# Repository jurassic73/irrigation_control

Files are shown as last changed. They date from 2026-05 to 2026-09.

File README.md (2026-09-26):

# Irrigation Control

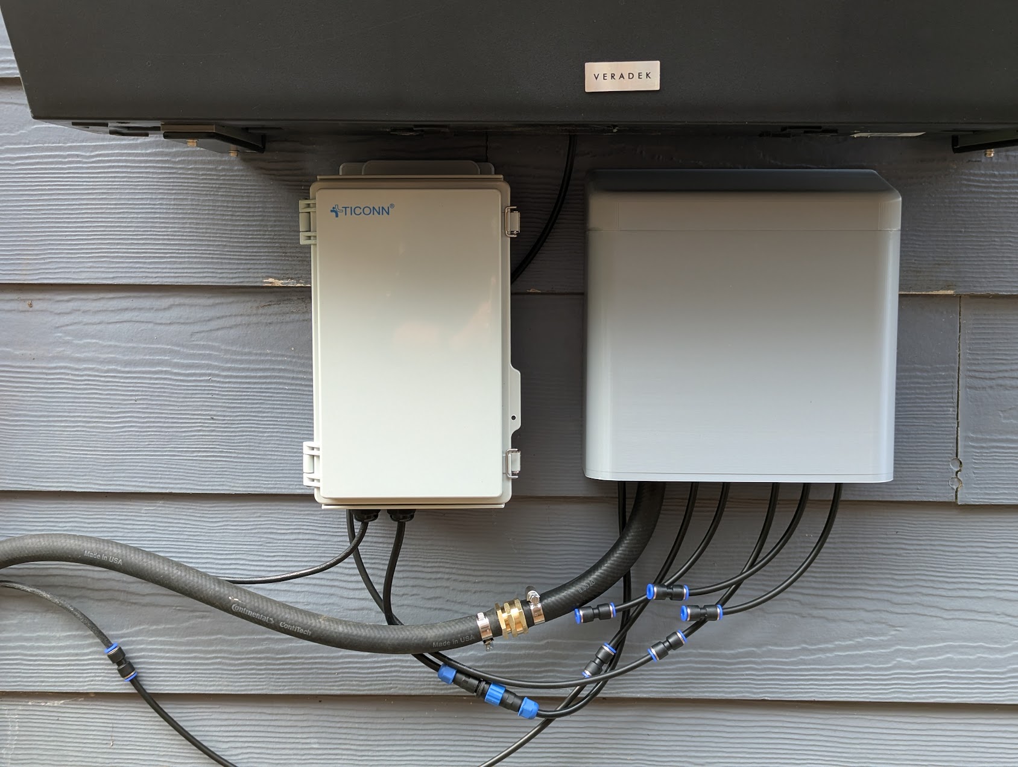
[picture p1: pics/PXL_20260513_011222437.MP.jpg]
Finished installation — control enclosure (left) and 3D printed solenoid valve enclosure (right) mounted on exterior wall


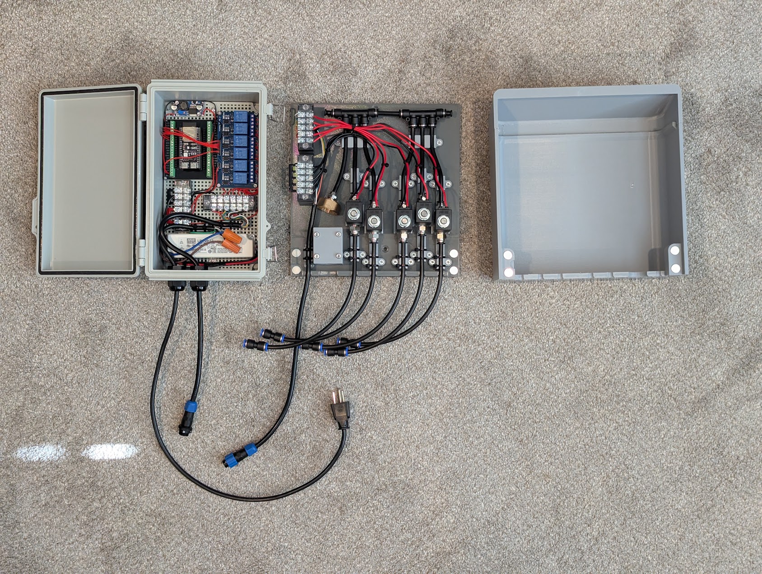
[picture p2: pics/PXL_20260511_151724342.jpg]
Build shot — control enclosure open (left), solenoid valve enclosure open (center), and 3D printed cover (right)


ESP32-S3 based irrigation controller with a mobile-friendly web UI. Controls up to 5 zones via relay board, enforces single-zone water pressure constraint via a FIFO queue, and runs two daily watering programs (Morning / Afternoon).

## Hardware

| Component | Detail |
| --- | --- |
| MCU | ESP32-S3-DevKitC-1-N8 |
| Status LED | WS2812 on GPIO 48 (onboard) |
| Relay outputs | GPIO 4, 5, 6, 7, 15 (active-low) |
| Relay board | 5-channel optocoupler relay, 12 V coils, 5 V logic VCC |
| Flow sensor | DIGITEN FL-S402B on GPIO 16 — Red→3.3 V, Black→GND, Yellow→GPIO 16 |

### LED status colors

- Green — standby, WiFi connected
- Blue — zone actively watering
- Off — booting / no WiFi

**Wiring note:** Use 5 V for relay board VCC (not 3.3 V). Disconnect USB-C before powering relays from 12 V supply.

**Plumbing note:** Apply Teflon tape to all NPT threaded fittings before installing into solenoid valves. Finger-tight connections will leak.

**Electronics enclosure note:** The TICONN box is waterproof and airtight, protecting all electronics from the elements. It hangs on a hook and connects via the AC cord and the 6-pin waterproof quick-disconnect, making it removable in seconds — if you need to bring it inside to update firmware, unplug both connections and take it in. Use the right USB-C port to flash code with no button pressing required.

**Valve enclosure note:** All valve housing connectors exit as quick-disconnects outside the housing. If you need to remove the enclosure for service, everything unplugs cleanly without disturbing the internal wiring.

**Chip temperature note:** On hot days the on-chip die temperature can read around 160 °F (71 °C). This is well within the ESP32-S3's maximum junction temperature spec of 125 °C (257 °F). At first glance 160 °F looks alarming, but it is normal and consistent with what other ESP32 users report when running inside an airtight enclosure exposed to direct sun.

## Parts List

Prices are approximate and subject to change.

### Electronics

| Image | Part | Description | ~Price | Link |
| --- | --- | --- | --- | --- |
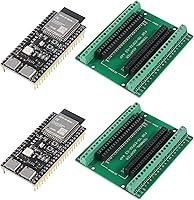
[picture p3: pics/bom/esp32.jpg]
ESP32-S3 dev board
|  | ESP32-S3 dev board | ESP32-S3-WROOM-1, 2-pack | ~$16 | [Amazon B0FF3XC4RZ](https://www.amazon.com/dp/B0FF3XC4RZ) |
| 12V power supply | 12 V power supply  | Powers relay coils and solenoid valves | ~$13 | [Amazon B00MEKJ4E2](https://www.amazon.com/dp/B00MEKJ4E2) |
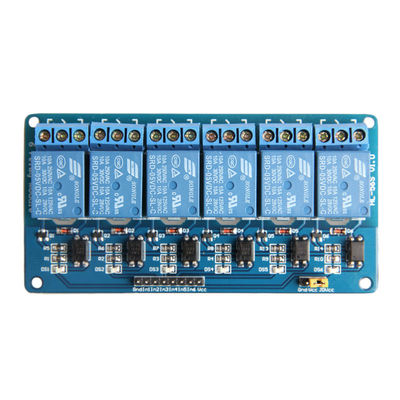
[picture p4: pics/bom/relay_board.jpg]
5-ch relay board
|  | 5-ch relay board | 5V optocoupler relay, 12 V coils | ~$5 | [AliExpress](https://www.aliexpress.us/w/wholesale-5v-relay-board-optocoupler.html) |
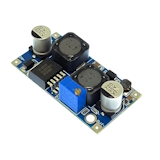
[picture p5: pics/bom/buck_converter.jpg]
Buck converter
|  | Buck converter | 12 V → 5 V step-down (powers ESP32) | ~$3 | [AliExpress](https://www.aliexpress.us/w/wholesale-step-down-buck.html) |
| Hall effect flow sensor | Flow sensor | DIGITEN FL-S402B, 1/4″ quick-connect, 0.3–10 L/min Hall effect — GPIO 16 | ~$9.50 | [Amazon search](https://www.amazon.com/s?k=1%2F4+Quick+Connect+0.3-10L%2Fmin+Water+Hall+Effect+Flow+Sensor+Meter) |

### Enclosure & Wiring

| Image | Part | Description | ~Price | Link |
| --- | --- | --- | --- | --- |
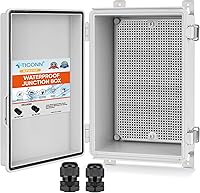
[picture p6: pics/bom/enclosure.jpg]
Waterproof enclosure
|  | Waterproof enclosure | TICONN IP67 ABS box, 10.2″ × 6.3″ × 3.9″, hinged lid, cable glands | ~$24 | [Amazon B0BND8Y3QN](https://www.amazon.com/dp/B0BND8Y3QN) |
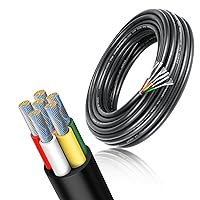
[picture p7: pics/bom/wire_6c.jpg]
6-conductor wire
|  | 6-conductor wire | RESHAKE 22 AWG 6C tinned copper stranded wire, 16.4 ft — zone wiring between enclosures | ~$12 | [Amazon B0C7MKBFNK](https://www.amazon.com/dp/B0C7MKBFNK) |
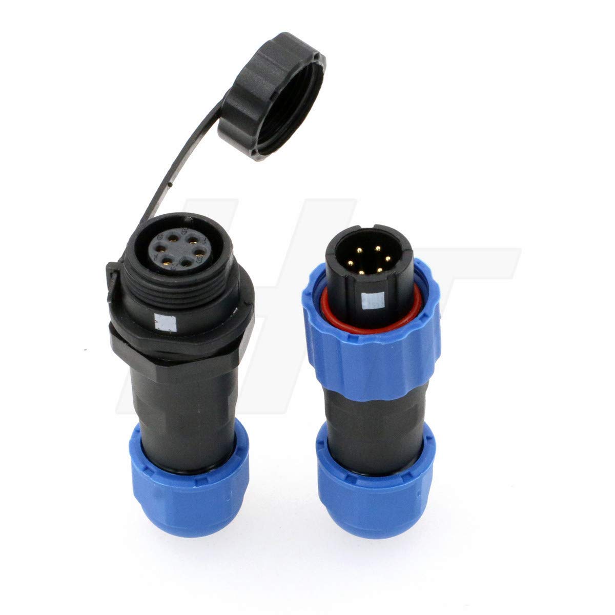
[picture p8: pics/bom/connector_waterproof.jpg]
Waterproof connector
|  | Waterproof connector | HangTon SD13 6-pin IP68 male/female plug set — inter-enclosure quick-disconnect | ~$12 | [Amazon B0894SSPVX](https://www.amazon.com/dp/B0894SSPVX) |
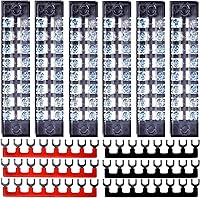
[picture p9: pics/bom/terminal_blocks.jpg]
Terminal blocks
|  | Terminal blocks | 12-pc screw terminal strip set, 600 V / 15 A | ~$10 | [Amazon B09QHSLJJ3](https://www.amazon.com/dp/B09QHSLJJ3) |

### Plumbing

System uses 1/4″ OD push-to-connect tubing throughout. One solenoid valve per zone.

| Image | Part | Description | ~Price | Link |
| --- | --- | --- | --- | --- |
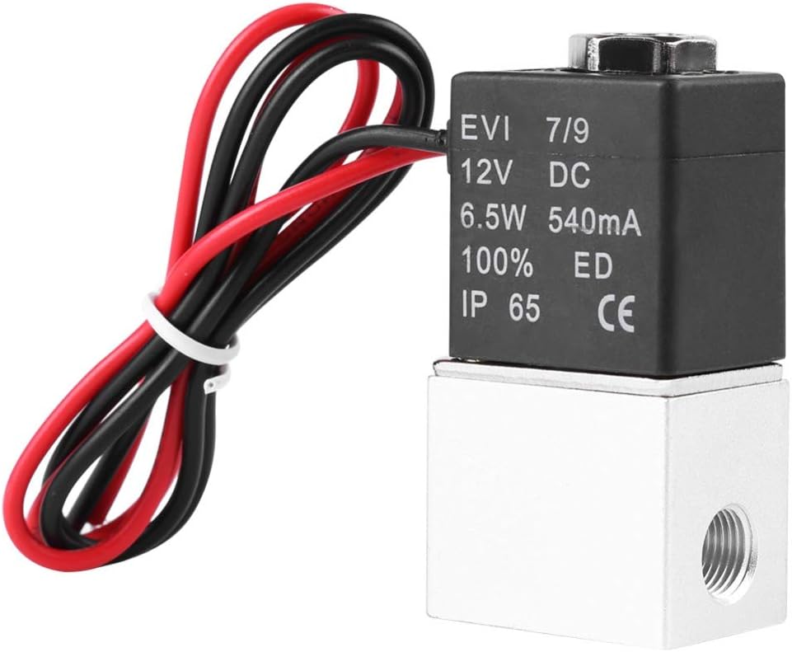
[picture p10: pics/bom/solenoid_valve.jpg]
Solenoid valve
|  | Solenoid valve | 12 V DC NC, 1/4″ NPT — one per zone | ~$10 each | [Amazon B07N2LGFYS](https://www.amazon.com/dp/B07N2LGFYS) |
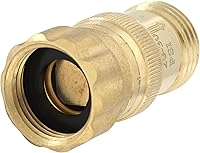
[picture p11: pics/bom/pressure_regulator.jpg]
Pressure regulator
|  | Pressure regulator  | 25 psi, 3/4″ hose thread, lead-free brass — protects drip system | ~$13 | [Amazon B0B1M42TVG](https://www.amazon.com/dp/B0B1M42TVG) |
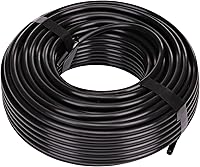
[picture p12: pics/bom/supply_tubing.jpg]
Supply tubing
|  | Supply tubing | Raindrip 1/4″ OD black poly, 100 ft — smooth outer layer for push-to-connect compatibility | ~$10 | [Amazon B0007WJIJU](https://www.amazon.com/dp/B0007WJIJU) |
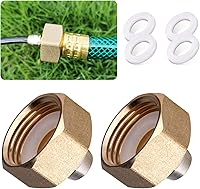
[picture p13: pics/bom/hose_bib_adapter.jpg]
Hose bib adapter
|  | Hose bib adapter | HOMENOTE 3/4″ female hose thread → 1/4″ tubing, 2-pack | ~$9 | [Amazon B089ZZPXLQ](https://www.amazon.com/dp/B089ZZPXLQ) |
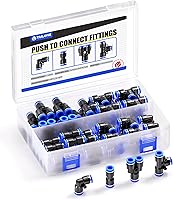
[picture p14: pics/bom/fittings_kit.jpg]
Fittings kit
|  | Fittings kit | TAILONZ 40-pc 1/4″ OD assortment — tees, elbows, straights, splitters | ~$14 | [Amazon B07RSLDDBR](https://www.amazon.com/dp/B07RSLDDBR) |
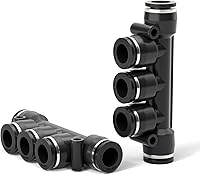
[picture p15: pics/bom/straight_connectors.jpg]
Straight connectors
|  | Straight connectors | TAILONZ 1/4″ OD push-to-connect, 5-pack | ~$9 | [Amazon B07SXRL8YR](https://www.amazon.com/dp/B07SXRL8YR) |
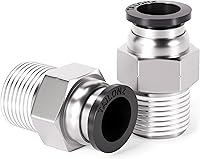
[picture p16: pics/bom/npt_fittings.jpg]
NPT male fittings
|  | NPT male fittings | TAILONZ 1/4″ OD × 1/4″ NPT male straight, 10-pack | ~$11 | [Amazon B07PBPB367](https://www.amazon.com/dp/B07PBPB367) |
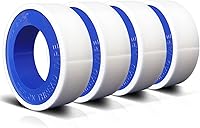
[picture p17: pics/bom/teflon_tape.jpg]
Teflon tape
|  | Teflon tape | PTFE thread seal tape, 1/2″ wide, 4-pack — for all NPT fittings | ~$5 | [Amazon B091913Z7F](https://www.amazon.com/dp/B091913Z7F) |

## 3D Printed Parts

The solenoid valve enclosure consists of two pieces, a base and a cover. Both consist of two parts due to my MK4s bed size. Used PETG for both as ASA warped too much to produce reliable, dimensionally accurate parts. I used Overture Space Gray PETG. The cover uses 12 mm rare earth magnets to secure when closed. Super glue holds the magnets in their holes.

The valve assembly parts are intentionally designed as separate, individually replaceable pieces.

The parts are segmented to fit the MK4s print bed. If you have a larger-format printer, open the STEP file (`stl/1_4_drip_irrigation_valve_housing.step`) in your CAD program to merge the halves into single pieces and clean up the seams. Always room for improvement — adapt it to your setup and submit a PR.

| Part | Perimeters | Infill |
| --- | --- | --- |
| Cover | 3 | 15% |
| Base (×2 halves) | 4 | 35% |
| Everything else | 2 | 15% |

### Assembly

1. **Base halves** — lightly tap the two halves together with a hammer until seated, then apply super glue along the seam to join permanently.
2. **Hardware mounting** — use wood screws to mount all hardware. 5/8″ screws work well for most mounting points.

## Commissioning Notes

### NPT fitting leaks

When I first pressurized the system I found leaks at three of the ten NPT fittings. Fix: depressurize the system, remove all five solenoids, and apply two full wraps of Teflon tape to every NPT fitting before reinstalling. Do them all at once rather than chasing leaks one at a time.

### Solenoid valve body leak

If water drips from the black valve body itself (not from a fitting), the internal o-ring needs reseating. To service:

1. Depressurize the system.
2. Remove the retaining nut — hand-tight, as it holds the solenoid coil on the cylinder but creates no seal. No torque needed.
3. Remove the solenoid coil.
4. Remove the two screws securing the end plate and pull the plate off.
5. Pull the cylinder out of the valve body.
6. Apply a thin coat of Super Lube synthetic silicone grease to the o-ring at the base of the cylinder.
7. Press the cylinder back into the valve body. Once fully seated, rotate it left and right about 90° to help the greased o-ring seat evenly and form a good seal.
8. Reinstall the end plate with the two screws.
9. Reinstall the solenoid coil and thread the retaining nut hand-tight. The end plate and its two screws handle all sealing — the nut retains the coil, nothing more.

## Software

- Framework: Arduino via PlatformIO
- Async HTTP server (ESPAsyncWebServer)
- Config persisted in NVS (ESP32 Preferences) — nonvolatile memory that survives firmware upgrades, so your zone names, schedules, and settings are safe when you flash new code
- Run, temperature, weather and change logs persisted to LittleFS — these also survive a firmware flash
- Embedded single-file HTML/CSS/JS UI served from PROGMEM

### Resource usage (current build)

| | Used | Available | % |
| ----- | --- | --- | --- |
| RAM | 57 KB | 320 KB | 18% |
| Flash | 1,075 KB | 3,264 KB  | 33% |

## Setup

1. Install [PlatformIO](https://platformio.org/).
2. Copy `src/secrets.h.example` to `src/secrets.h` and fill in your WiFi credentials:

   ```cpp
   const char* WIFI_SSID = "your_ssid";
   const char* WIFI_PASS = "your_password";
   ```
3. Copy `src/location.h.example` to `src/location.h` and fill in your coordinates (used for weather-based watering adjustments):

   ```cpp
   #define WEATHER_LAT  45.633   // your latitude
   #define WEATHER_LON -122.490  // your longitude
   ```

   Both `secrets.h` and `location.h` are gitignored so your credentials and location stay off GitHub.

5. Connect the ESP32-S3 via the **right USB-C port** (labeled USB on the board). This port uses native USB and handles bootloader mode automatically — no button pressing required for uploads or reboots. The left port (UART) requires holding BOOT then pressing RESET to enter download mode.
6. Build and upload:

   ```text
   pio run --target upload
   ```
7. Open a browser to the ESP32's IP address (printed on serial at 115200 baud).

## Web UI

The web UI runs directly on the ESP32 — no app, no cloud, no external server. Open a browser on any device on the same network and you're in. If your router supports VPN (such as WireGuard or OpenVPN), you can VPN into your home network from anywhere and access the controller as if you were home.

### Zones

Each zone appears as a card showing its name, active status, and a **Run Now** button. When a zone has a duration configured for a program, a colored pill label shows the program name and duration at a glance. Below the pill labels, a row of day buttons shows which days that zone participates in that program — blue for Morning, violet for Afternoon. Day buttons are read-only when collapsed.

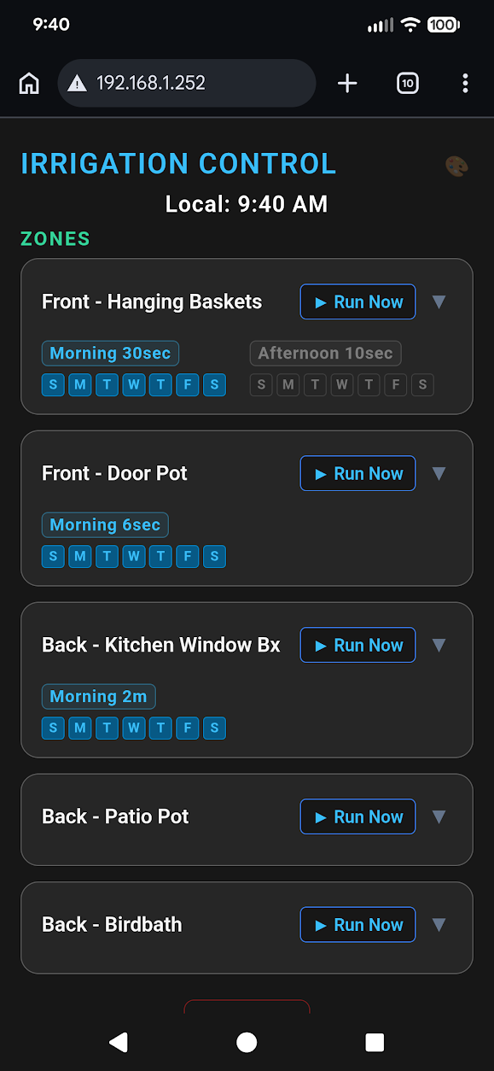
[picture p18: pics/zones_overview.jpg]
Zone list — collapsed view showing pill labels and day-of-week indicators
> 

At the right-hand end of the day-button row, a **power switch** parks the zone for
the season. Switched off, the zone is skipped by both scheduled runs and program
**Run Now**, but its durations and day masks are kept exactly as they were — so the
timings you dialled in over the summer are still there next spring. A parked zone
renders greyed out. A single-zone **Run Now** still works as an explicit manual
override, so you can always test a parked zone.

Tap the arrow to expand a zone. The day buttons become interactive so you can toggle individual days per program. The duration inputs let you set minutes and seconds independently for Morning and Afternoon.

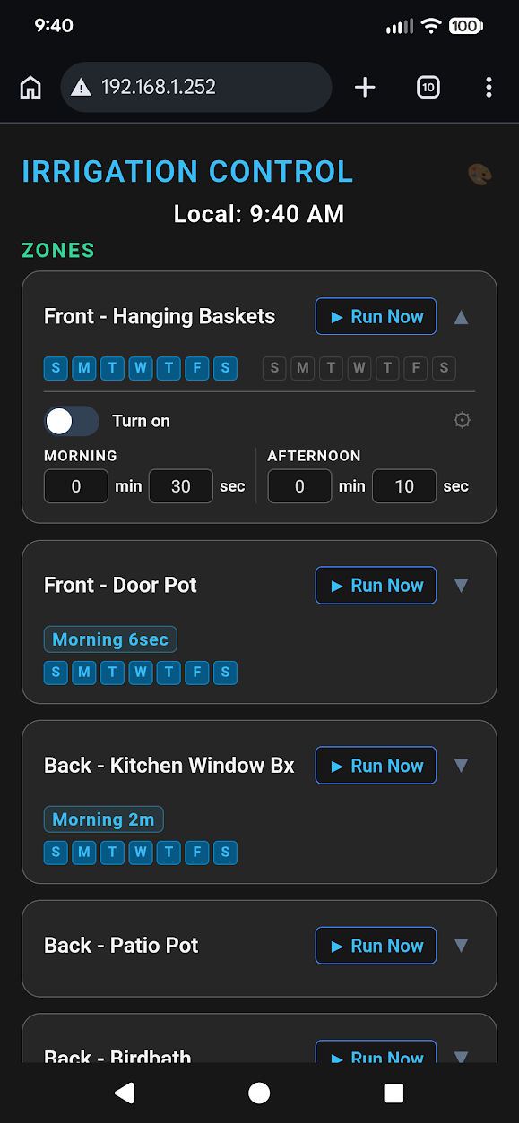
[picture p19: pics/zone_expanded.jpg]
Zone expanded — duration inputs and interactive day toggles
> 

Tap the gear icon inside an expanded zone to open the configuration panel where you can rename the zone and change its GPIO pin.

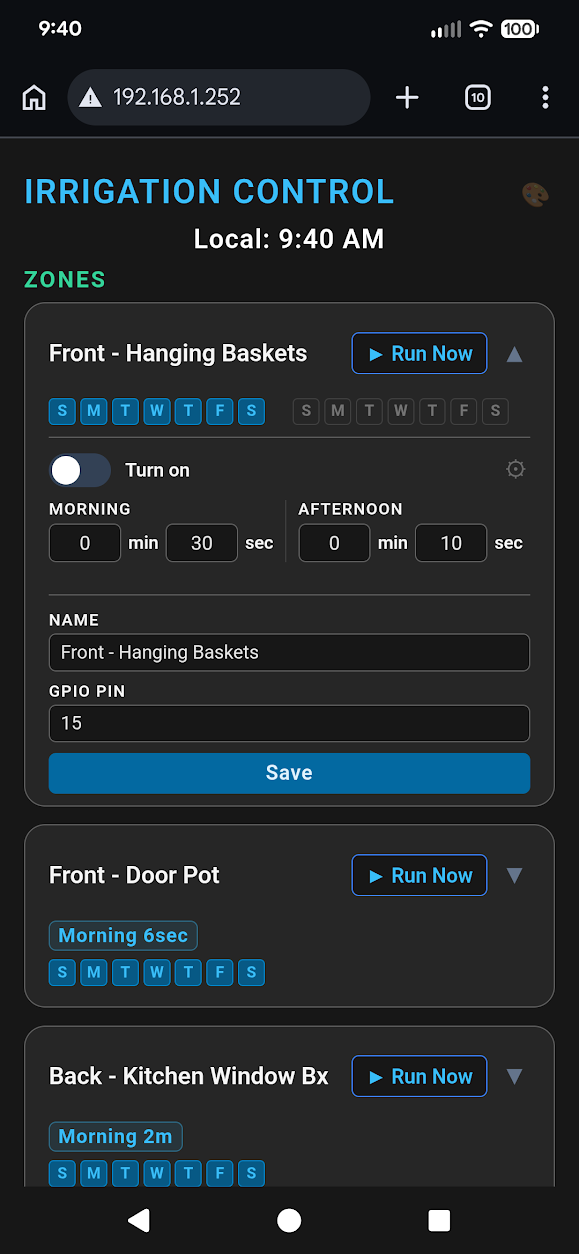
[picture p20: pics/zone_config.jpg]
Zone expanded — name and GPIO pin configuration
> 

### Run Now

Tap **Run Now** on any zone to open the run dialog. It offers that zone's configured
Morning and Afternoon durations as one-tap presets — colour-matched to the schedule
pills — or tap **Custom** to dial in an exact duration.

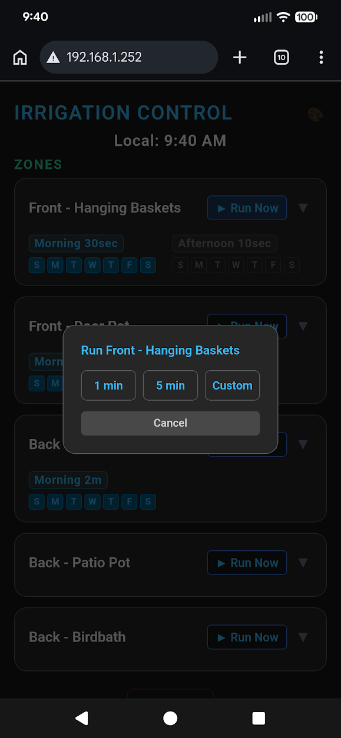
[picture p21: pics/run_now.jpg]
Run Now — quick-select presets
> 

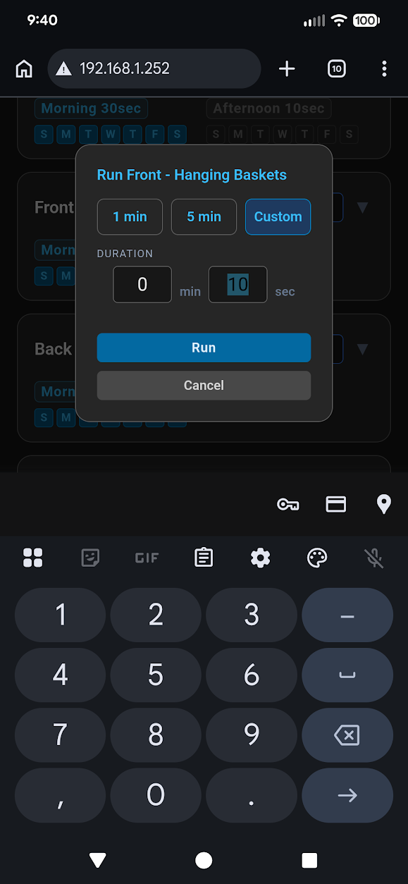
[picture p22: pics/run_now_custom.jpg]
Run Now — custom duration entry
> 

The zone is queued immediately. All other Run Now buttons disable while any zone is running or queued to prevent pressure conflicts. Use **All Off** to stop the active zone and clear the queue instantly.

### Programs

Two watering programs — Morning and Afternoon — each have an independent time, day-of-week mask, and enable toggle. Changes save to flash automatically when you interact with any control.

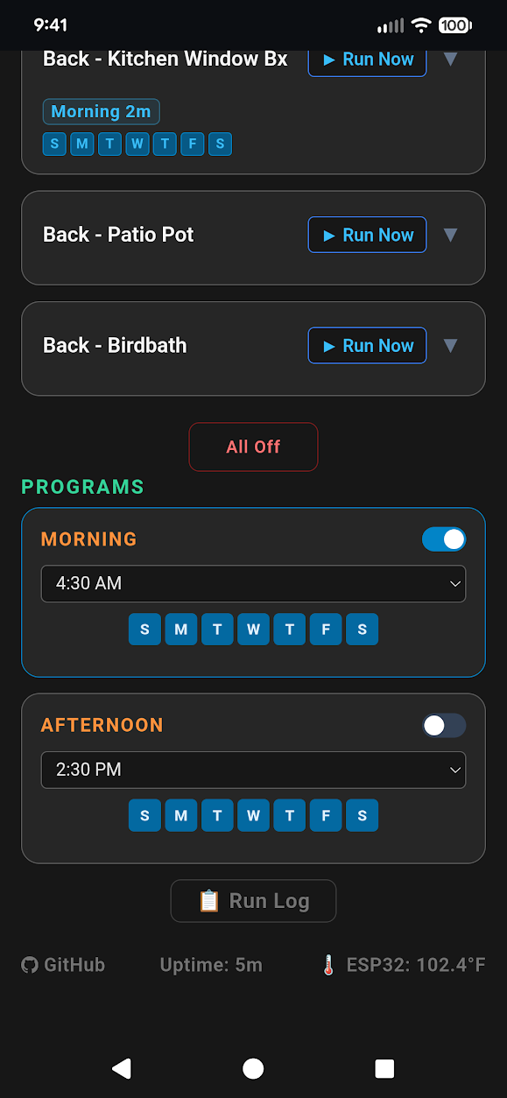
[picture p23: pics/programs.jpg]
Programs — Morning enabled at 4:30 AM daily, Afternoon disabled
> 

Each zone independently opts in or out of a program on a per-day basis using the day toggles on the zone card. A zone only waters when **both** the program's day mask **and** the zone's own day mask include that day of the week. This lets you run some zones every day while others water only on certain days, all within the same program schedule.

### Flow Monitoring

The flow sensor measures actual water delivered per zone run, auditing for upstream pressure problems (failing pressure regulator, supply starvation) and per-zone issues (clogged drip emitters, broken lines).

#### Wiring

Install the sensor inline on the main supply line — upstream of the solenoid valves so all zones flow through it.

| Wire | Connect to |
| --- | --- |
| Red | 3.3 V |
| Black  | GND |
| Yellow | GPIO 16 (signal)|

**Sensor spec (DIGITEN FL-S402B):** F = 23 × Q(L/min) — approximately 1,380 pulses/liter or **~5,220 pulses/gallon** theoretical. Always run the in-app calibration for your specific installation; actual values vary with pressure and fittings.

#### Calibration

1. Wire the sensor and flash firmware with flow sensor support enabled.
2. Open the web UI and tap **Flow Cal** (to the right of the weather badge).
3. Select the zone to run during calibration (defaults to Zone 5). Choose a zone that flows through the sensor.
4. Verify **Flow Sensor GPIO Pin** is set to **16**.
5. Have a clean 1-gallon measuring jug ready at the zone outlet.
6. Tap **▶ Start Cal** — the selected zone turns on and pulse counting begins.
7. Allow water to flow until the jug reaches exactly **1 gallon**, then tap **■ Stop Cal**.
8. The zone stops and the counted pulses auto-populate the **Pulses per Gallon** field. Review and adjust if needed.
9. Set your **Low-flow alarm threshold** (default 75% — alarm triggers when a run delivers less than 75% of the baseline flow rate).
10. Tap **Save**.

#### Baseline learning and low-flow alarms

After calibration, the firmware auto-learns a per-zone flow baseline from the first 3 valid runs (runs ≥ 30 seconds with measured flow). Progress is shown in the Flow Cal modal next to each zone name.

Once a baseline is established for a zone:

- If a run's flow rate drops **below the alarm threshold** (default 75% of baseline), a persistent red banner appears at the top of the page on the next visit: **"Low flow detected: Zone X — possible upstream pressure issue or clogged emitters. Check run logs."**
- The banner is dismissible for the current session, but reappears on the next page load until the alarm clears.
- When subsequent runs return to within spec, the alarm **clears automatically**.
- To reset a zone's baseline (e.g., after intentionally changing emitters), open **Flow Cal**, select the zone, and tap **Reset Baseline for Selected Zone**.

The **Flow Adjustment row** below the weather badge shows today's and this week's total gallons delivered across all zones, along with the active GPIO pin and pulses/gallon setting. It is hidden until the sensor is calibrated.

The **Run Log** shows a blue gallon figure next to each run's duration once flow data
is available, and the CSV export includes a **Water (gal)** column. Volumes are stored
to the hundredth of a gallon and displayed with two decimals below 1 gal, because drip
zones routinely deliver 0.03–0.7 gal per run — at tenth-gallon resolution most runs
recorded as `0.0`, which also made the low-flow check see zero flow and raise false
alarms. The low-flow rate is computed from raw sensor pulses rather than the rounded
volume, so display precision and alarm accuracy are independent.

Retention is set from the **Keep _n_ days** field in the Run History panel header
(1–90 days, default 7).

### Additional features

- **All Off** — stops the active zone and clears the entire queue.
- **Run countdown** — the active zone's badge counts down the time remaining, ticking every second between the 15-second state polls.
- **Run Log** — opens a modal showing watering history grouped by day and program, newest first. Includes per-run gallon measurements once the flow sensor is calibrated.
- **Chip temperature** — live ESP32 die temperature in the bottom bar. Tap to open a history graph with **1 Day** and **1 Week** views. Auto-refreshes every 60 seconds while open. Samples recorded every 10 minutes (up to 1,008, persisted to LittleFS so they survive a reboot).
- **Uptime** — time since last boot, updated every 15 seconds.
- **Theme** — 🎨 icon cycles dark → light → color. Preference saved in localStorage.

## API Endpoints

**Read-only endpoints are `GET`. Every state-changing endpoint is `POST`.** A `GET`
against a `POST` endpoint returns 404. This keeps a stray `<img src="http://host/alloff">`
on some other page — or a link prefetcher, or a crawler — from actuating a valve.
Parameters still travel in the query string either way, so `POST /relay?id=0&state=1`
needs no request body.

### Read (GET)

| Endpoint | Params | Description |
| --- | --- | --- |
| `/` | — | The web UI, with the current state inlined so the first paint needs no round trip |
| `/config` | — | JSON snapshot of full state — see fields below |
| `/history` | — | Run history, newest first; includes `retainDays` and `count` |
| `/changelog` | — | Configuration change log, up to 50 entries |
| `/weatherlog` | — | Last 7 weather fetches, newest first, successes and failures |
| `/temp` | — | Current chip die temperature as `{"c": 52.3, "f": 126.1}` |
| `/temphistory` | `secs` (default 604800) | Temperature samples at 10-min intervals — up to 144 for 24 h, up to 1008 for 7 days |
| `/flowcal/stop`  | — | Returns `{"pulses": N}` — the value to use as pulses/gallon. Reads the counter; does not stop it  |

### Write (POST)

| Endpoint | Params | Description |
| --- | --- | --- |
| `/relay` | `id`, `state` (0/1), `secs` (optional) | Queue a zone, or stop it and drop it from the queue. `secs`, not minutes |
| `/alloff` | — | Stop the active zone and clear the queue |
| `/runprogram` | `id` | Queue a program's zones immediately, skipping switched-off zones |
| `/setzone` | `id`, `name`, `pin`, `en`, `d0`…`dN`, `zd0`…`zdN` | Zone name, GPIO pin, power switch, per-program durations **in seconds**, per-program day masks |
| `/sethistory` | `days` | Retention window, 1–90 days. Also settable from the Run History panel header |
| `/setprogram` | `id`, `en`, `h`, `m`, `days` | Program enable, time and day mask (bit 0 = Sunday) |
| `/setcoolpct` | `pct` | Cool-day watering percentage, 10–90 |
| `/sethotpct` | `pct` | Hot-day watering percentage, 100–200 |
| `/setweatherconds` | `htf`, `hwk`, `hof`, `ctf`, `ccp`, `cpx` | Hot/cool thresholds: temp °F, wind kph, override °F, cool °F, cloud %, precip ×10 mm |
| `/fetchweather` | — | Trigger an immediate weather fetch on the background task |
| `/pushcl` | `e` (URL-encoded JSON) | Append a change-log entry |
| `/clearcl` | `confirm=1` | Erase the change log. Without `confirm=1` returns 400 — it is destructive |
| `/flowcal/start` | — | Zero the pulse counter before filling the calibration jug |
| `/setflow` | `pin`, `ppg` | Flow sensor GPIO pin and pulses-per-gallon |
| `/setflowthresh` | `pct` | Low-flow alarm threshold, 10–99; default 75 |
| `/dismissflowalarm` | — | Hide the current low-flow banner until a fresh alarm occurs |
| `/resetflowbaseline`  | `zone` | Clear one zone's baseline and alarm; re-learns over the next 3 runs |

### `/config` fields of note

| Field | Meaning |
| --- | --- |
| `activeZone` | Index of the running zone, or `-1` |
| `activeEnd` | Unix time the active run ends, or `0` — drives the countdown on the zone badge |
| `queued` | Zone indices waiting, in order |
| `chipF` | Chip die temperature in °F |
| `weatherScale` | Active watering percentage, 100 unless the day read hot or cool |
| `zones[].enabled` | `false` when the zone's power switch is off — durations are retained |
| `zfBase` / `zfCnt` | Per-zone flow baseline (gal/min ×100) and how many learning runs have landed |

### `/history` response example

```json
{
  "retainDays": 7,
  "count": 3,
  "history": [
    {
      "zone": 2,
      "name": "Back Garden",
      "trigger": "Morning",
      "start": 1746000000,
      "durationSecs": 300,
      "gallonsX100": 237,
      "lowFlow": 0
    }
  ]
}
```

### `/temphistory` response example

```json
[
  {"t": 1746000000, "f": 124.3},
  {"t": 1746000600, "f": 125.1}
]
```

## Failure Behaviour

An irrigation controller fails badly if it leaves a valve open, so the firmware is
arranged to end up with the water off:

- **Hung firmware** — `loopTask` is subscribed to the ESP32 task watchdog (5 s, panic
  mode). If the main loop ever wedges, the chip reboots, and `setup()` drives every
  relay off before it touches anything else.
- **Power loss** — the solenoids are normally-closed, so no power means no water.
- **Router down at boot** — the boot-time WiFi wait is bounded at 60 s. The controller
  finishes booting without a network and `loop()` retries every 30 s, so a power cut
  that takes the router down alongside the controller recovers on its own.
- **NTP unavailable** — schedules pause rather than firing at the wrong time, and
  resume automatically once the clock syncs, however late that is.
- **Run length** — capped at `MAX_RELAY_SECS` (8 h) after weather scaling, not before.

## Scheduling

A single water pressure source means one relay runs at a time. The scheduler uses a FIFO queue:

- When a program fires it enqueues all enabled zones back-to-back.
- A manual Run Now enqueues that zone at the head of the queue.
- Turning a zone off removes it from the queue and stops it if active.

Run history lives in a 200-entry circular buffer, mirrored to LittleFS (`hist.bin`) so
it survives a reboot, and purges to the configured retention window after each run.

Writes to flash are deferred: HTTP handlers run on the async server task, which must
not block, so they flag what changed and the main loop performs the NVS and LittleFS
writes on its next pass.

A zone waters only when its power switch is on, the program's day mask includes today,
**and** the zone's own day mask includes today.

## File Structure

```text
irrigation_control/
├── platformio.ini
├── partitions.csv            # 8 MB layout: dual OTA app slots + 1.5 MB LittleFS
├── irrigation-widget.html    # Standalone desktop widget (reads /config and /temp)
├── src/
│   ├── main.cpp              # All firmware + embedded HTML UI
│   ├── secrets.h             # WiFi credentials (gitignored)
│   ├── secrets.h.example
│   ├── location.h            # Latitude/longitude for weather (gitignored)
│   └── location.h.example
├── stl/                      # 3D-printable enclosure parts
├── pics/                     # README screenshots and BOM thumbnails
└── README.md
```

Logs are kept on the LittleFS partition as `hist.bin`, `temp.bin`, `wlog.bin` and
`clog.json`. Flashing firmware leaves them alone; writing a filesystem image with
`pio run -t uploadfs` would erase all four.

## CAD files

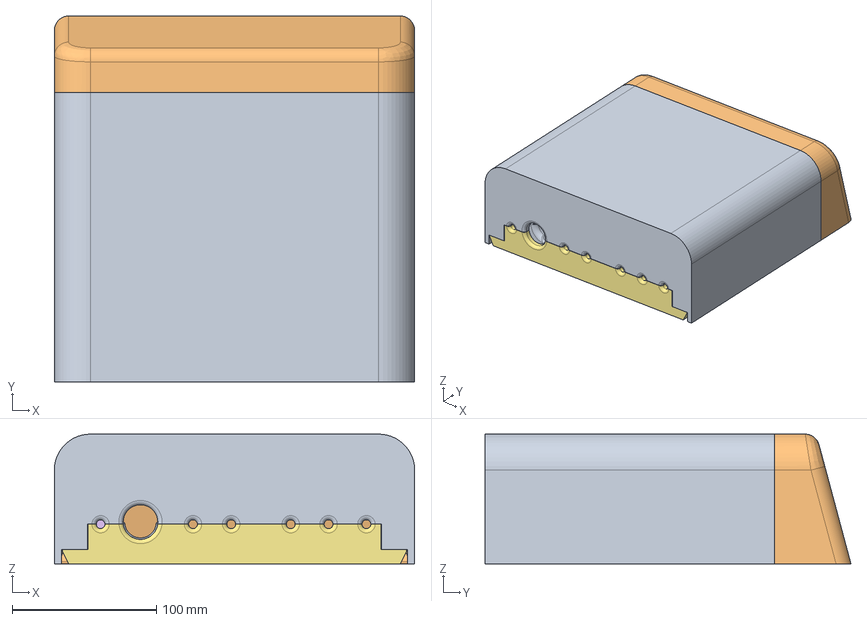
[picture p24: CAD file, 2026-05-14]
stl/1_4_drip_irrigation_valve_housing.step
250.0 x 253.9 x 90.0 mm
hose_keeper_base (1)
hose_keeper_cap (1)

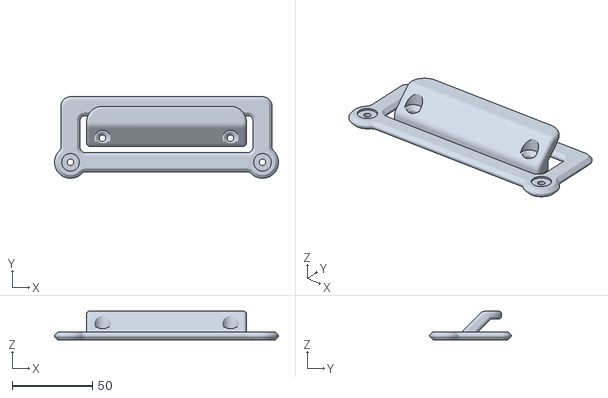
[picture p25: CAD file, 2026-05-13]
stl/box_hook.stl
140.0 x 51.0 x 18.0

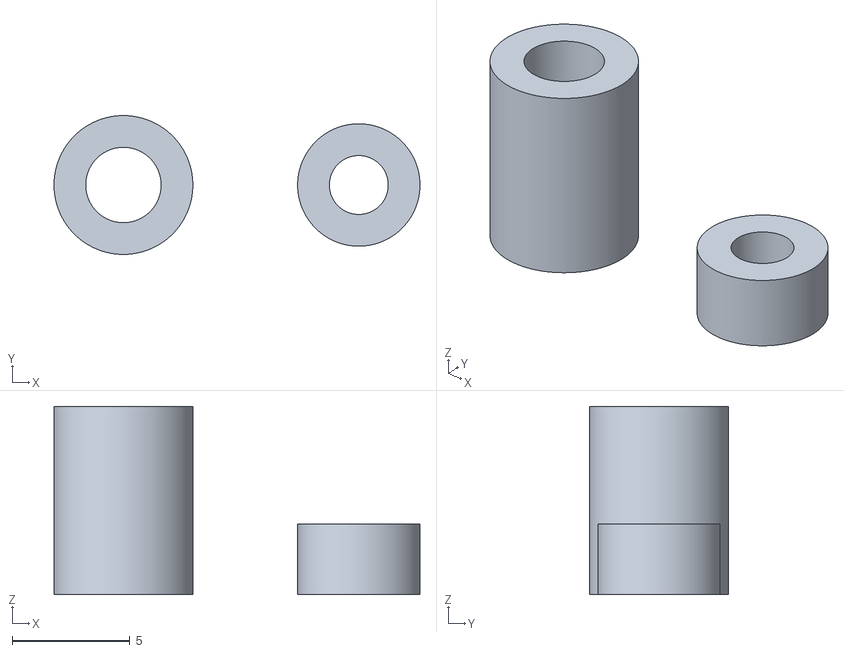
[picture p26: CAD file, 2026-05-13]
stl/board_spacers.stl
15.6 x 5.90 x 8.00

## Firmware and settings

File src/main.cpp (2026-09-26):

#include <Arduino.h>
#include <WiFi.h>
#include <AsyncTCP.h>
#include <ESPAsyncWebServer.h>
#include <Preferences.h>
#include <LittleFS.h>
#include <time.h>
#include <Adafruit_NeoPixel.h>
#include <HTTPClient.h>
#include <WiFiClientSecure.h>
#include <ArduinoJson.h>
#include "secrets.h"
#include "location.h"

#define FW_VERSION        "1.2.1"

#define LED_PIN      48
#define LED_COUNT     1
#define NUM_ZONES     5
#define NUM_PROGRAMS  2
#define QUEUE_MAX    (NUM_ZONES * NUM_PROGRAMS)

#define MAX_RELAY_SECS   28800UL   // 8 hours — hard cap on any single zone run
#define WEATHER_SLEEP_MS (30UL * 60UL * 1000UL)  // 30-minute retry interval

Adafruit_NeoPixel led(LED_COUNT, LED_PIN, NEO_GRB + NEO_KHZ800);

const bool  RELAY_ACTIVE_LOW = true;
static const char* TZ_PACIFIC = "PST8PDT,M3.2.0,M11.1.0";

uint8_t relayPins[NUM_ZONES]      = {4, 5, 6, 7, 15};
char    relayNames[NUM_ZONES][32] = {"Zone 1","Zone 2","Zone 3","Zone 4","Zone 5"};

struct WateringProgram { bool enabled; uint8_t hour, minute, days; };
const char* PROG_NAMES[NUM_PROGRAMS] = {"Morning", "Afternoon"};
WateringProgram programs[NUM_PROGRAMS] = {
  {true,  5, 30, 0x7F},
  {true, 15, 30, 0x7F},
};
time_t progLastFired[NUM_PROGRAMS] = {};

uint16_t zoneDuration[NUM_ZONES][NUM_PROGRAMS] = {};
// bit i = zone i participates in scheduled runs. Switching a zone off preserves its
// durations and day masks — the point is parking a zone for the season without
// having to remember and re-enter last year's settings.
uint8_t  zoneEnabledBits = 0xFF;
uint8_t  zoneDays[NUM_ZONES][NUM_PROGRAMS]     = {};

struct QEntry { uint8_t zone; uint32_t secs; uint8_t trigger; }; // trigger: 0=manual, 1+=program id+1
QEntry  qBuf[QUEUE_MAX];
int     qHead = 0, qSize = 0;
int8_t  activeZone      = -1;
time_t  activeEndTime   = 0;
time_t  activeStartTime = 0;
uint8_t activeTrigger   = 0;

// ESPAsyncWebServer callbacks run on Core 0; loop() runs on Core 1.
// stateMux guards all shared queue and active-zone state between the two tasks.
// flowMux guards flowPulseCount between the FALLING-edge ISR and task context.
static portMUX_TYPE stateMux = portMUX_INITIALIZER_UNLOCKED;
static portMUX_TYPE flowMux  = portMUX_INITIALIZER_UNLOCKED;

#define HISTORY_MAX 200
// trigger byte: low 7 bits = trigger id (0=manual, 1+=program), bit 7 = low-flow detected this run
#define HIST_LOWFLOW 0x80
// gallonsX100 = hundredths of a gallon. Tenths truncated almost every drip-zone run
// to zero, which also fed checkFlowRate a zero rate and produced false low-flow alarms.
struct HistoryEntry { time_t start; uint16_t duration; uint8_t zone; uint8_t trigger; uint16_t gallonsX100; };
HistoryEntry history[HISTORY_MAX];
int histHead = 0, histCount = 0;
uint8_t historyDays = 7;

#define TEMP_HIST_MAX 1008
struct TempSample { time_t t; float c; };
TempSample tempHist[TEMP_HIST_MAX];
int tempHistHead = 0, tempHistCount = 0;
unsigned long lastTempSample = 0;

uint8_t coolDayPct    = 50;   // % to water on cool/overcast days (persisted)
uint8_t hotDayPct     = 150;  // % to water on hot/windy days (persisted)
uint8_t weatherScale  = 100;  // active scale factor — RAM only, resets to 100 on reboot
uint8_t hotTempF      = 90;   // hot-day min temp threshold °F (persisted)
uint8_t hotWindKph    = 24;   // hot-day min wind threshold kph (persisted)
uint8_t hotOverrideF  = 85;   // at/above this temp, cloud/low-temp can't force a cool day (persisted)
uint8_t coolTempF     = 65;   // cool-day max temp threshold °F (persisted)
uint8_t coolCloudPct  = 80;   // cool-day min cloud cover % (persisted)
uint8_t coolPrecipX10 = 25;   // cool-day min precip ×10 mm (25 = 2.5 mm) (persisted)
time_t  lastWeatherFetch = 0;
time_t  lastWeatherAttempt = 0;
volatile bool weatherFetchActive = false;
static TaskHandle_t weatherTaskHandle = NULL;

uint8_t  flowPin             = 16;
uint32_t flowPulsesPerGallon = 0;       // 0 = not calibrated
volatile uint32_t flowPulseCount = 0;
uint32_t activeStartPulses   = 0;

// Atomic snapshot of the ISR-updated pulse counter from task context.
static inline uint32_t readFlowPulses() {
  portENTER_CRITICAL(&flowMux);
  uint32_t v = flowPulseCount;
  portEXIT_CRITICAL(&flowMux);
  return v;
}

#define FLOW_BASELINE_RUNS 3            // runs needed to establish per-zone baseline
uint16_t zoneFlowBaseline[NUM_ZONES]    = {};  // gal/min * 100; 0 = still learning
uint8_t  zoneBaselineCount[NUM_ZONES]   = {};  // valid runs accumulated so far
uint32_t zoneBaselineSum[NUM_ZONES]     = {};  // sum of rateX100 during learning
uint8_t  zoneFlowAlarmBits              = 0;   // bitmask: bit i = zone i has low-flow alarm
uint8_t  zoneFlowAlarmDismissed         = 0;   // bitmask: bit i = alarm dismissed for this instance
uint8_t  flowAlarmThreshPct             = 75;  // alarm when flow < this % of baseline

#define WEATHER_LOG_MAX 7
struct WeatherLogEntry { time_t t; float maxF, precip, cloud, wind; uint8_t scale; bool ok; int16_t errCode; bool manual; };
WeatherLogEntry wLog[WEATHER_LOG_MAX];
int wLogCount = 0, wLogHead = 0;

String clJson = "[]";
SemaphoreHandle_t clMux = nullptr;  // guards clJson between HTTP callbacks and the deferred write
Preferences       prefs;
SemaphoreHandle_t prefsMux = nullptr;  // guards all Preferences access across cores
bool timeValid = false;  // set true only after a successful NTP sync

// ── Deferred persistence ──────────────────────────────────────────────────────
// ESPAsyncWebServer callbacks run on the AsyncTCP task, which must not block: a
// saveConfig() there is ~60 NVS keys and a saveHistoryLog() is a 2.4 KB LittleFS
// write, both stalling every other connection. Handlers set a dirty bit instead and
// loop() does the actual write on its next pass (flushDirty).

#define DIRTY_CONFIG   0x01
#define DIRTY_PURGE    0x02   // trim history to the retention window (runs before the write)
#define DIRTY_HISTORY  0x04
#define DIRTY_TEMP     0x08
#define DIRTY_WLOG     0x10
#define DIRTY_CLOG     0x20

static uint8_t dirtyFlags = 0;
static portMUX_TYPE dirtyMux = portMUX_INITIALIZER_UNLOCKED;

static void markDirty(uint8_t bits) {
  portENTER_CRITICAL(&dirtyMux);
  dirtyFlags |= bits;
  portEXIT_CRITICAL(&dirtyMux);
}

// ── Log persistence (LittleFS) ────────────────────────────────────────────────

void saveHistoryLog() {
  File f = LittleFS.open("/hist.bin", "w");
  if (!f) { Serial.println("saveHistoryLog: open failed"); return; }
  f.write((uint8_t*)&histHead,  sizeof(histHead));
  f.write((uint8_t*)&histCount, sizeof(histCount));
  f.write((uint8_t*)history,    sizeof(history));
  f.close();
  Serial.printf("saveHistoryLog: %d entries written\n", histCount);
}

void saveTempHistory() {
  File f = LittleFS.open("/temp.bin", "w");
  if (!f) { Serial.println("saveTempHistory: open failed"); return; }
  f.write((uint8_t*)&tempHistHead,  sizeof(tempHistHead));
  f.write((uint8_t*)&tempHistCount, sizeof(tempHistCount));
  f.write((uint8_t*)tempHist,       sizeof(tempHist));
  f.close();
  Serial.printf("saveTempHistory: %d entries written\n", tempHistCount);
}

void saveWeatherLog() {
  File f = LittleFS.open("/wlog.bin", "w");
  if (!f) { Serial.println("saveWeatherLog: open failed"); return; }
  f.write((uint8_t*)&wLogHead,  sizeof(wLogHead));
  f.write((uint8_t*)&wLogCount, sizeof(wLogCount));
  f.write((uint8_t*)wLog,       sizeof(wLog));
  f.close();
  Serial.printf("saveWeatherLog: %d entries written\n", wLogCount);
}

void saveChangeLog() {
  // clJson is mutated by /pushcl on the AsyncTCP task while this runs on loop()'s.
  if (clMux) xSemaphoreTake(clMux, portMAX_DELAY);
  File f = LittleFS.open("/clog.json", "w");
  if (f) { f.print(clJson); f.close(); }
  else Serial.println("saveChangeLog: open failed");
  if (clMux) xSemaphoreGive(clMux);
}

void loadLogs() {
  // Directory listing for diagnostics
  File root = LittleFS.open("/");
  if (root) {
    File entry = root.openNextFile();
    if (!entry) Serial.println("LittleFS: filesystem empty");
    while (entry) {
      Serial.printf("LittleFS: %s  %u bytes\n", entry.name(), entry.size());
      entry = root.openNextFile();
    }
    root.close();
  }

  auto loadBin = [](const char* path, void* a, size_t sa, void* b, size_t sb, void* c, size_t sc) {
    File f = LittleFS.open(path, "r");
    if (!f) { Serial.printf("loadLogs: %s not found\n", path); return; }
    size_t got = f.size(), expect = sa + sb + sc;
    if (got != expect) {
      Serial.printf("loadLogs: %s size mismatch (got %u expect %u)\n", path, got, expect);
      f.close(); return;
    }
    f.read((uint8_t*)a, sa);
    f.read((uint8_t*)b, sb);
    f.read((uint8_t*)c, sc);
    f.close();
  };

  loadBin("/hist.bin", &histHead, sizeof(histHead), &histCount, sizeof(histCount), history, sizeof(history));
  loadBin("/temp.bin", &tempHistHead, sizeof(tempHistHead), &tempHistCount, sizeof(tempHistCount), tempHist, sizeof(tempHist));
  loadBin("/wlog.bin", &wLogHead, sizeof(wLogHead), &wLogCount, sizeof(wLogCount), wLog, sizeof(wLog));

  // loadBin only validates file size, so head/count still come straight off flash.
  // A corrupt-but-right-sized file would otherwise index out of bounds: purgeHistory
  // and addHistory use histHead unwrapped, and a negative count makes
  // (head + count) % MAX negative. Drop the ring rather than trust garbage.
  auto clampRing = [](const char* what, int& head, int& count, int cap) {
    if (count < 0 || count > cap || head < 0 || head >= cap) {
      Serial.printf("loadLogs: %s ring invalid (head=%d count=%d cap=%d) — discarding\n",
                    what, head, count, cap);
      head = 0; count = 0;
    }
  };
  clampRing("hist", histHead,     histCount,     HISTORY_MAX);
  clampRing("temp", tempHistHead, tempHistCount, TEMP_HIST_MAX);
  clampRing("wlog", wLogHead,     wLogCount,     WEATHER_LOG_MAX);

  // Rescale tenths-of-a-gallon entries written before the precision fix, and drop the
  // flow baselines learned from them — those were derived from truncated volumes, so
  // checking accurate rates against them would misfire. They re-learn over 3 runs.
  {
    if (prefsMux) xSemaphoreTake(prefsMux, portMAX_DELAY);
    Preferences mp; mp.begin("irr", false);
    bool migrate = mp.getUChar("logVer", 0) < 1;
    if (migrate) mp.putUChar("logVer", 1);
    mp.end();
    if (prefsMux) xSemaphoreGive(prefsMux);
    if (migrate) {
      for (int i = 0; i < histCount; i++) {
        HistoryEntry& e = history[(histHead + i) % HISTORY_MAX];
        uint32_t v = (uint32_t)e.gallonsX100 * 10U;
        e.gallonsX100 = (uint16_t)(v > 65535U ? 65535U : v);
      }
      for (int z = 0; z < NUM_ZONES; z++) {
        zoneFlowBaseline[z] = 0; zoneBaselineCount[z] = 0; zoneBaselineSum[z] = 0;
      }
      zoneFlowAlarmBits = 0; zoneFlowAlarmDismissed = 0;
      Serial.printf("Log migration: rescaled %d entries to hundredths, reset flow baselines\n", histCount);
      markDirty(DIRTY_HISTORY | DIRTY_CONFIG);
    }
  }

  Serial.printf("Logs loaded: hist=%d temp=%d wlog=%d\n", histCount, tempHistCount, wLogCount);
  { File f = LittleFS.open("/clog.json", "r"); if (f) { clJson = f.readString(); f.close(); } }
}

void pushWeatherLog(time_t t, float maxF, float precip, float cloud, float wind, uint8_t scale, bool ok, int16_t errCode = 0, bool manual = false) {
  int idx = (wLogHead + wLogCount) % WEATHER_LOG_MAX;
  wLog[idx] = {t, maxF, precip, cloud, wind, scale, ok, errCode, manual};
  if (wLogCount < WEATHER_LOG_MAX) wLogCount++;
  else wLogHead = (wLogHead + 1) % WEATHER_LOG_MAX;
  markDirty(DIRTY_WLOG);
}

AsyncWebServer    server(80);

inline float toF(float c) { return c * 9.0f / 5.0f + 32.0f; }

void addTempSample(time_t t, float c) {
  int idx = (tempHistHead + tempHistCount) % TEMP_HIST_MAX;
  tempHist[idx] = {t, c};
  if (tempHistCount < TEMP_HIST_MAX) tempHistCount++;
  else tempHistHead = (tempHistHead + 1) % TEMP_HIST_MAX;
  markDirty(DIRTY_TEMP);
}

// ── Queue ─────────────────────────────────────────────────────────────────────

void enqueue(uint8_t z, uint32_t secs, uint8_t trigger = 0) {
  portENTER_CRITICAL(&stateMux);
  if (qSize < QUEUE_MAX)
    qBuf[(qHead + qSize++) % QUEUE_MAX] = {z, secs, trigger};
  portEXIT_CRITICAL(&stateMux);
}

QEntry dequeue() {  // must be called while holding stateMux
  QEntry e = qBuf[qHead];
  qHead = (qHead + 1) % QUEUE_MAX;
  qSize--;
  return e;
}

void clearQueue() {
  portENTER_CRITICAL(&stateMux);
  qSize = 0;
  portEXIT_CRITICAL(&stateMux);
}

void removeFromQueue(int z) {
  portENTER_CRITICAL(&stateMux);
  QEntry tmp[QUEUE_MAX]; int n = 0;
  for (int i = 0; i < qSize; i++) {
    QEntry e = qBuf[(qHead + i) % QUEUE_MAX];
    if (e.zone != (uint8_t)z) tmp[n++] = e;
  }
  qHead = 0; qSize = n;
  memcpy(qBuf, tmp, n * sizeof(QEntry));
  portEXIT_CRITICAL(&stateMux);
}

// ── LED ───────────────────────────────────────────────────────────────────────

void updateLED() {
  if (activeZone >= 0) {
    led.setBrightness(70);
    led.setPixelColor(0, led.Color(0, 0, 255));
  } else {
    led.setBrightness(30);
    led.setPixelColor(0, led.Color(0, 255, 0));
  }
  led.show();
}

// ── Flow sensor ───────────────────────────────────────────────────────────────

void saveConfig();  // forward declaration — defined after loadConfig

// Evaluate a completed zone run against its flow baseline.
// rateX100 = gal/min * 100.  Skips short/zero-flow runs during learning phase.
// Returns true if this run came in below the low-flow threshold.
bool checkFlowRate(uint8_t zone, uint32_t pulsesUsed, uint16_t durSecs) {
  if (zone >= NUM_ZONES || flowPulsesPerGallon == 0) return false;
  if (durSecs < 30) return false;                   // too short to be meaningful
  // gal/min * 100, straight from pulses: pulses * 60 / ppg / durSecs, scaled by 100.
  // Deriving this from the rounded volume made every sub-0.1 gal run read as zero flow.
  uint32_t rateX100 = (uint32_t)((uint64_t)pulsesUsed * 6000ULL /
                                 ((uint64_t)flowPulsesPerGallon * durSecs));

  if (zoneFlowBaseline[zone] == 0) {
    // still in learning phase — only accumulate positive readings
    if (rateX100 == 0) return false;
    zoneBaselineSum[zone] += rateX100;
    zoneBaselineCount[zone]++;
    if (zoneBaselineCount[zone] >= FLOW_BASELINE_RUNS) {
      zoneFlowBaseline[zone] = (uint16_t)(zoneBaselineSum[zone] / FLOW_BASELINE_RUNS);
      Serial.printf("Zone %d flow baseline: %.2f gal/min (%d runs)\n",
        zone, zoneFlowBaseline[zone] / 100.0f, FLOW_BASELINE_RUNS);
      markDirty(DIRTY_CONFIG);   // persist completed baseline
    }
    return false;
  }

  // baseline established — check against threshold
  uint32_t threshold = (uint32_t)zoneFlowBaseline[zone] * flowAlarmThreshPct / 100;
  bool wasAlarm = (zoneFlowAlarmBits >> zone) & 1;
  bool isLow    = rateX100 < threshold;
  if (isLow) {
    if (!wasAlarm) {
      zoneFlowAlarmBits      |= (1 << zone);
      zoneFlowAlarmDismissed &= ~(1 << zone);   // fresh instance — show banner again
      markDirty(DIRTY_CONFIG);
      Serial.printf("Zone %d LOW FLOW: %.2f gal/min (baseline %.2f, threshold %d%%)\n",
        zone, rateX100 / 100.0f, zoneFlowBaseline[zone] / 100.0f, flowAlarmThreshPct);
    }
  } else {
    if (wasAlarm) {
      zoneFlowAlarmBits      &= ~(1 << zone);
      zoneFlowAlarmDismissed &= ~(1 << zone);
      markDirty(DIRTY_CONFIG);
      Serial.printf("Zone %d flow alarm cleared: %.2f gal/min\n", zone, rateX100 / 100.0f);
    }
  }
  return isLow;
}

void IRAM_ATTR flowPulseISR() {
  portENTER_CRITICAL_ISR(&flowMux);
  flowPulseCount++;
  portEXIT_CRITICAL_ISR(&flowMux);
}

void setupFlowSensor(uint8_t newPin) {
  static bool attached = false;
  if (attached) detachInterrupt(digitalPinToInterrupt(flowPin));  // skip on first boot — nothing to detach yet
  flowPin = newPin;
  pinMode(flowPin, INPUT_PULLUP);
  attachInterrupt(digitalPinToInterrupt(flowPin), flowPulseISR, FALLING);
  attached = true;
}

// ── Relay ─────────────────────────────────────────────────────────────────────

void setRelay(int idx, bool on) {
  bool pinOn = RELAY_ACTIVE_LOW ? !on : on;
  digitalWrite(relayPins[idx], pinOn ? HIGH : LOW);
  updateLED();
}

void purgeHistory() {
  time_t now; time(&now);
  time_t cutoff = now - (time_t)historyDays * 86400;
  if (histCount == 0 || history[histHead].start >= cutoff) return;
  HistoryEntry tmp[HISTORY_MAX]; int n = 0;
  for (int i = 0; i < histCount; i++) {
    HistoryEntry& e = history[(histHead + i) % HISTORY_MAX];
    if (e.start >= cutoff) tmp[n++] = e;
  }
  histHead = 0; histCount = n;
  memcpy(history, tmp, n * sizeof(HistoryEntry));
}

void addHistory(HistoryEntry e) {
  if (histCount >= HISTORY_MAX) {
    history[histHead] = e;
    histHead = (histHead + 1) % HISTORY_MAX;
  } else {
    history[(histHead + histCount) % HISTORY_MAX] = e;
    histCount++;
  }
  markDirty(DIRTY_PURGE | DIRTY_HISTORY);
}

// requireZone >= 0 stops only if that zone is currently active; -1 stops whatever is active.
void stopActive(int requireZone = -1) {
  portENTER_CRITICAL(&stateMux);
  if (activeZone < 0 || (requireZone >= 0 && activeZone != requireZone)) {
    portEXIT_CRITICAL(&stateMux);
    return;
  }
  time_t now; time(&now);
  long     elapsed    = (long)(now - activeStartTime);
  if (elapsed < 0) elapsed = 0;          // clock stepped backwards mid-run
  uint16_t dur        = (uint16_t)(elapsed > 65535L ? 65535L : elapsed);
  int8_t   zone       = activeZone;
  uint8_t  trig       = activeTrigger;
  time_t   start      = activeStartTime;
  uint32_t startPulses= activeStartPulses;
  activeZone = -1; activeEndTime = 0; activeStartTime = 0;
  portEXIT_CRITICAL(&stateMux);
  uint32_t pulsesUsed = readFlowPulses() - startPulses;
  uint16_t gallonsX100 = 0;
  if (flowPulsesPerGallon > 0) {
    uint64_t v = (uint64_t)pulsesUsed * 100ULL / flowPulsesPerGallon;
    gallonsX100 = (uint16_t)(v > 65535ULL ? 65535ULL : v);
  }
  bool lowFlow = checkFlowRate((uint8_t)zone, pulsesUsed, dur);
  if (lowFlow) trig |= HIST_LOWFLOW;
  addHistory({start, dur, (uint8_t)zone, trig, gallonsX100});
  setRelay(zone, false);
  Serial.printf("Zone %d (%s) done after %us\n", zone, relayNames[zone], dur);
}

void allOffFn() {
  clearQueue(); stopActive();
  for (int i = 0; i < NUM_ZONES; i++) setRelay(i, false);
}

// ── Persistence ───────────────────────────────────────────────────────────────
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
void loop() {
  static unsigned long lastSched = 0;
  static unsigned long lastWifiRetry = 0;
  static bool wifiWasDown = false;
  unsigned long now_ms = millis();
  runQueue();
  bool wifiUp = (WiFi.status() == WL_CONNECTED);

  // SNTP keeps running in the background and often lands well after setup() gave up
  // (slow router, WiFi only up later). Without this retry, one failed boot-time sync
  // would leave checkSchedules() disabled until someone power-cycled the controller.
  if (!timeValid && wifiUp) {
    time_t t; time(&t);
    if (t > 1700000000) {            // 2023-11-14 — safely past the un-synced default
      timeValid = true;
      Serial.println("NTP synced late — schedules resumed");
      expireStaleWeatherScale();
    }
  }

  if (!wifiUp) {
    if (now_ms - lastWifiRetry > 30000) {
      lastWifiRetry = now_ms;
      if (!wifiWasDown) Serial.println("WiFi disconnected — first reconnect attempt");
      else              Serial.println("WiFi still down — retrying reconnect");
      wifiWasDown = true;
      WiFi.reconnect();
    }
  } else if (wifiWasDown) {
    wifiWasDown = false;
    Serial.printf("WiFi reconnected, IP: %s\n", WiFi.localIP().toString().c_str());
    time_t t; time(&t);
    if (t - lastWeatherFetch > 43200 && t - lastWeatherAttempt > 60) {
      Serial.println("Weather: triggering fetch after WiFi recovery");
      if (weatherTaskHandle) xTaskNotify(weatherTaskHandle, 0UL, eSetValueWithOverwrite);
    }
  }
  if (now_ms - lastSched >= 15000) {
    lastSched = now_ms;
    checkSchedules();
    time_t now; struct tm ti{}; time(&now); localtime_r(&now, &ti);
    { int mMin = programs[0].hour * 60 + programs[0].minute;
      int fMin = ((mMin - 120) + 1440) % 1440;
      bool inWindow = (ti.tm_hour == fMin/60 && ti.tm_min >= fMin%60);
      bool cooldown = !weatherFetchActive && (now - lastWeatherAttempt > 900);
      if (cooldown) {
        struct tm lastFetchTm{};
        if (lastWeatherFetch > 0) localtime_r(&lastWeatherFetch, &lastFetchTm);
        bool notFetchedToday = (lastWeatherFetch == 0 ||
                                lastFetchTm.tm_year != ti.tm_year ||
                                lastFetchTm.tm_yday != ti.tm_yday);
        if (notFetchedToday) {
          int nowMin = ti.tm_hour * 60 + ti.tm_min;
          int retryEnd = (fMin + 120) % 1440;
          bool inRetryZone = (fMin < retryEnd)
              ? (nowMin >= fMin && nowMin < retryEnd)
              : (nowMin >= fMin || nowMin < retryEnd);
          if (inRetryZone) {
            if (inWindow)
              Serial.println("Weather: triggering scheduled pre-program fetch");
            else
              Serial.printf("Weather: retry fetch (%dm after window open)\n", (nowMin - fMin + 1440) % 1440);
            if (weatherTaskHandle) xTaskNotify(weatherTaskHandle, 0UL, eSetValueWithOverwrite);
          }
        }
      }
    }
  }
  if (now_ms - lastTempSample >= 600000UL) {
    lastTempSample = now_ms;
    time_t now; time(&now);
    addTempSample(now, temperatureRead());
  }

  flushDirty();   // NVS/LittleFS writes deferred by the HTTP handlers

  // Everything above is gated on millis() deltas, so spinning flat out only burned
  // power and starved the WiFi/lwIP tasks sharing this core.
  delay(50);
}

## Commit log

2026-05-09 Fixed days of the week not being selectable.
    [main.cpp]
2026-05-13 Added 3d printed parts
    [board_spacers.stl, box_hook.stl]
2026-05-14 Fixed CPU queue utilizaion
    [main.cpp]
2026-05-20 Update - adding persistence to logs through power cycles with time limiting purges to avoid filling up storage over time
    [partitions.csv]
2026-05-20 Updated log window behavior
    [partitions.csv]
2026-05-21 Performance and reliability improvements
    - Inline config JSON in initial HTML response to eliminate second round-trip on page load
    - Move weather fetch to FreeRTOS task so it no longer blocks loop() or the UI
    - Fix prefs concurrency race between weather task and web handler task
    - Increase weather task stack 12K→16K for TLS headroom
    - Fix manualFetch button stuck disabled on error; extend wait to cover full retry window
    - Add try/catch to fetchConfig so transient failures don't silently stop polling
    - Remove unused relayState[] array
    [main.cpp]
2026-05-21 Fix beginResponse arg order to match AwsResponseFiller streaming overloadThe streaming overload signature is beginResponse(contentType, len, callback),not beginResponse(statusCode, contentType, callb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
    [main.cpp]
2026-05-26 Updated to add retry mechanism to weather fetch over longer period to work around server issues
    [main.cpp]
2026-05-27 Add WiFi-aware weather fetch failsafes and verbose logging
    After a WiFi drop, the previous code immediately broke out of the retry
    loop on http.begin() failure (code -1) with no further attempts, leaving
    weather data stale for the rest of the day. Zones continued to run at the
    last known scale with no recovery path until the next day's pre-program window.
    Changes:
    - fetchWeather: check WiFi status before each attempt; if down, call
    reconnect() and wait up to 15s before proceeding; http.begin failure
    now continues to next retry instead of breaking; -1 added to transient
    error set so connection failures are retried like 5xx/timeout errors
    - loop: track wifiWasDown flag; log first discon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
    [main.cpp]
2026-06-11 Fixed double run of weather fetch overlapping
    [main.cpp]
2026-09-26 Fix four correctness bugs in scheduler, weather scale, and log loading
    1. NTP failure at boot no longer freezes schedules permanently. timeValid was
    set only in setup(), so a slow router meant checkSchedules() stayed disabled
    until a manual power cycle even though SNTP synced minutes later. loop() now
    re-checks the clock while WiFi is up.
    2. The weather scale can no longer push a run past MAX_RELAY_SECS. hotDayPct
    reaches 200%, which scaled an 8h zone to 16h despite the documented hard cap.
    New scaledDuration() applies the scale, the 1s floor and the cap in one place,
    replacing the duplicated arithmetic in checkSchedules() and /runprogram.
    3. weatherScale now survives a r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
    [main.cpp]
2026-09-26 Move blocking writes off the AsyncTCP task; harden change log; add run countdown
    Deferred persistence. HTTP handlers ran saveConfig() (~60 NVS keys) and
    saveHistoryLog() (2.4 KB LittleFS) directly on the AsyncTCP task, which must not
    block — every other connection stalled behind them. Handlers now set a dirty bit
    and loop() performs the write via flushDirty(). Flags are claimed under a spinlock
    so a handler firing mid-flush re-arms its bit instead of losing the write.
    addHistory() no longer calls purgeHistory() inline either: that function puts a
    2.4 KB HistoryEntry[200] frame on the stack even on its early-out path, and
    retention trimming does not need to happen in the request path.
    clJs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
    [main.cpp]
2026-09-26 Add a per-zone power switch that parks a zone without losing its schedule
    Disabling a zone previously meant zeroing its durations, which threw away the
    timings that were dialled in over the season. Switching a few zones off for winter
    therefore meant re-deriving last year's settings come spring.
    Each zone tile now carries a sliding switch at the bottom right of the day-button
    row. Off means scheduled runs skip the zone while its durations and day masks stay
    exactly as they were. Program "Run Now" honours the switch too, since that runs the
    program as configured; a single-zone "Run Now" still works as an explicit manual
    override. A parked zone renders greyed out so its state reads at a glanc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
    [main.cpp]
2026-09-26 Require POST for mutations, add touch drag, collapse duplicate change-log code
    Every state-changing endpoint was a GET, so any page on the network could actuate
    a valve or rewrite config with <img src="http://host/alloff">, and a link
    prefetcher or crawler could do it by accident. The 17 mutating endpoints are now
    POST; the 8 read-only ones stay GET because irrigation-widget.html fetches /config
    and /temp cross-origin. Query parameters still ride in the URL, so handler bodies
    are unchanged. This does not close CSRF completely — a cross-origin form POST is
    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
2026-09-26 Bring docs in line with the firmware and bump to 1.2.0
    The API section opened with "All endpoints are HTTP GET", which stopped being true
    when the mutating endpoints moved to POST. It also listed 15 of the 25 endpoints
    and documented two parameters that do not exist: /relay takes secs rather than
    mins, and /setzone durations are seconds, not minutes — they have been seconds
    since the cfgVer 2 migration. Rewritten as separate read and write tables covering
    every endpoint, plus a table of the /config fields worth knowing about.
    Other drift corrected: temperature history is persisted to LittleFS rather than
    lost on reboot; Run Now offers the zone's configured program durations as presets,
    no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
    [main.cpp]
2026-09-26 Fix flow volume resolution and the false low-flow alarms it caused
    Run volumes were stored in tenths of a gallon, computed as pulses * 10 / ppg. With
    the calibrated 7,734 pulses/gallon, a 45-second drip run delivering 0.037 gal
    truncated to 0. Most runs in the log therefore recorded 0.0 gal.
    Worse, checkFlowRate derived its rate from that truncated volume, so a healthy zone
    whose run rounded to zero was measured at zero gal/min and flagged low-flow. Four of
    the eighteen entries in the live log carry a false alarm flag for this reason, and
    zones 2 and 3 were sitting on standing alarms.
    Volumes are now hundredths of a gallon — same uint16_t, so the persisted struct size
    is unchanged and ex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
    [main.cpp]
2026-09-26 Arm the loop watchdog, bound the boot WiFi wait, clamp run duration
    Three failure paths that all end with water running when it should not.
    A hung loop() was unrecoverable. Nothing else closes a relay, so a wedged main loop
    left the valve open indefinitely. loopTask is now subscribed to the task watchdog,
    which this build compiles in with panic mode and a 5 s timeout; setup() drives every
    relay off before anything else, so a reboot lands in the safe state. loop() returns
    about every 50 ms, so the margin is large.
    The boot-time WiFi wait was an unbounded while loop. A power cut takes the router
    down alongside the controller and the router usually comes back slower, so the
    controller could s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
    [main.cpp]
